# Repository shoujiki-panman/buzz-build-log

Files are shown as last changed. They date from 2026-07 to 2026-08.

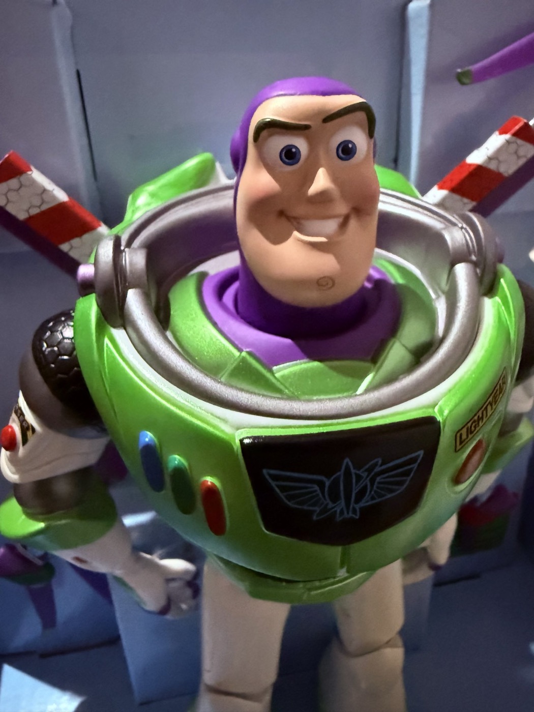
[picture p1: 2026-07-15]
buzz_photo.jpg

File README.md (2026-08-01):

# PROJECT BUZZ — 実フィギュアのバズを、本当に飛ばす

トイストーリーのバズ・ライトイヤーのアクションフィギュア（約264g）を、
実際に飛行するクアッドコプターに改造する個人プロジェクトのビルドログ。

- はんだ未経験の会社員が、AIと分担しながら作る「バイブコーディングをハードウェアに拡張する実験」
- 進捗はXで公開中: [#PROJECTBUZZ](https://x.com/hashtag/PROJECTBUZZ)
- **非営利のファンプロジェクト**です。キャラクターを使う成果物で収益化は行いません

## ゴール

**2026年10月末、バズが部屋を飛ぶ動画を1本公開する。**

進め方の原則: 計測→原因特定→1変更→検証 の1周を守る。シミュレータで通った＝実機OKとは考えない。
ハードは巻き戻せないため、各フェーズの合格条件（テスト）を満たすまで次に進まない。

## フェーズ（章立て）

| 章 | 内容 | 合格条件（=テスト） | 状態 |
|---|---|---|---|
| 第一章 | バズを目視で飛ばす（画面越しでなく自分の目で見て操縦） | 屋内で1分間の安定飛行 | **進行中**（調達完了・輸送待ち） |
| 第0.5章 | （廃止）操縦の練習は、シミュレータではなくテザー（命綱）で係留した実機で行う方針に変更 | — | 廃止（フェーズ8に統合） |
| 第二章 | 実機にFPVカメラを載せる準備 | — | 凍結（第一章の初飛行成功が条件） |
| 第三章 | AI自律飛行（専用実験機を想定） | 3モーションが実機で各1回成功 | 構想のみ。`sitl/` `motion/` が先行資産 |

### 第一章の詳細フェーズ（上から順に。1フェーズ完了→次へ）

各フェーズに **期日** を入れた。ゴール（11月の発表会）から逆算し、**2割の余裕**を持たせてある
（本来ギリギリの日付より1ヶ月手前に置く）。迷ったら、状態が「⬜次」の一番上の行が、いまやること。

| # | フェーズ | 期日（〜まで） | 誰が | やること | 合格条件（これで次へ） | 状態 |
|---|---|---|---|---|---|---|
| 1 | 発注 | 7/20 | オーナー | Futaba T6L（モード1）＋**受信機R3006SB**を注文（付属R3106GFはS.BUS非対応と判明・Issue #9） | 注文確定メール | ✅ **7/28発注済み**（8日遅れ・予備期間から充当） |
| 2 | 開封・検品 | 7/31 | オーナー | 全部品を開封し写真。モーターは手で回して異音チェック | 全部品そろい・破損なしの写真 | ✅ **7/29完了**（モーター4基・スタック・送信機T6L/受信機R3006SB。技適マーク001-A12854を実物確認） |
| 3 | 採寸 | 7/31 | オーナー→Claude | 素体264g確定・モーター実測済み・上蓋は共締め方式に変更（Issue #2） | 原寸紙型が実物と一致 | ✅ 設計反映済み（紙型照合はカーボン切り出し前に実施） |
| 3.4 | **実測** | **8/6** | オーナー | ノギス（8/4着）で羽根・背中・ジェットパックを測る（notes/MEASURE_LIST.md） | 表の空欄が埋まっている | ⬜ ノギス待ち |
| 3.5 | 発注 第2弾 | **8/8** | オーナー→Claudeがリンク準備 | プロペラ(紫)・バッテリー4S・充電器・ストリッパー・**デジタルノギス**=8/1注文済み。フレーム材はアルミに変更（3Dプリント・カーボン加工は廃止）→残りはホームセンターで**アルミ板＋平棒**（角パイプは設計変更で不要に。寸法は実測後に確定） | 全件の注文確定メール＋アルミ材購入 | 🔁 通販分✅・**実測後にホームセンター** |
| 4 | はんだ練習 | 8/10 | オーナー | 練習基板で10接点。玉が安定するまで | 玉の形が安定した写真 | ⬜ |
| 5 | 通電設定 | 8/17 | オーナー→Claude | スタックのBluetoothを無線オフに。USBでBetaflight設定 | 発煙なし・電圧正常・無線オフ確認 | ✅ **7/28前倒し完了**（BTFL 4.4.2接続・UART4オフ） |
| 6 | モーター回転確認 | 8/24 | オーナー | **ペラなし**で4モーターの回転方向を合わせる | 4基とも正しい向きで回る動画 | ⬜ |
| 7 | 素体ホバリング | **8/31** | オーナー | フィギュアなしの機体だけで浮かせる | 30秒の安定ホバリング動画 | ⬜ |
| 8 | バズ統合 | 9/21 | オーナー→Claude | バズを載せ、テザー（命綱）で係留して浮かせる | 係留状態で安定する動画 | ⬜ |
| 9 | 自由飛行・撮影 | **9/30** | オーナー | 屋内で目視飛行 | 1分の飛行動画（=第一章クリア） | ⬜ |

**発注第2弾の締切根拠**: カーボン板の切り出しは納期1〜2週間 → 素体ホバリング（8/31）から逆算して8/8注文が下限。
バッテリー・充電器はフェーズ6（モーター回転確認 8/24）までに初充電を済ませる必要があるため同時に買う。

**期日の意味（マイルストーン）:**
- **8/31 = 素体ホバリング**（フェーズ7）。ここが最重要関門。撤退基準「9月末までに浮かなければ縮小」より1ヶ月手前に置いてある＝失敗しても9月まるごとやり直せる
- **9/30 = 第一章クリア**（バズが飛ぶ）
- **10/15 = 動画完成**（公開の2週間前）／ **10月末 = 動画公開**
- **11月末（仮）= 発表会**。ここまでに全部終わり、発表練習だけの状態にする ← ⚠️正確な日付が分かり次第、全期日を前倒し調整

- **フェーズ7の前に必ず: 電波の運用ルール確認**（[Issue #7](../../issues/7)）。屋内限定・技適済みFutabaのみ使用
- 各フェーズ完了時に notes に「写真1枚＋一言」を残す（それが上の完了事項の表を育てる）
- **遅れたら**: 1フェーズ遅れるごとに、9月の予備1ヶ月から充当する。予備を使い切ったら仕様を落とす（重り妥協・自律を手動に・演出をテザー固定に）

### 設計・検証（Claude担当・荷物と並行して進む）

| 内容 | 状態 | 成果物 |
|---|---|---|
| トッププレート設計 | ✅ | [cad/top_plate.scad](cad/top_plate.scad) |
| 全体アセンブリの幾何チェック | ✅ | [cad/ASSEMBLY_CHECK.md](cad/ASSEMBLY_CHECK.md) |
| バズ3Dスキャン→メッシュ化 | ✅（v1。要トリミング） | [cad/buzz_mesh_v1.ply](cad/buzz_mesh_v1.ply) |
| スキャン2回目でメッシュ精度UP | ⬜ | 腕・支柱を近距離で撮り直す |
| アーム/モーターマウントのCAD | ⬜ 採寸後 | — |

### 発信トラック（ビルドと並走。作りっぱなしにせず毎週1本出す）

このプロジェクトは「作る」と「発信する」が並走する。ビルドの各フェーズが**そのまま動画の1話**になる。
毎週1本の制作サイクル = **撮る → 台本1枚 → 編集（縦型15〜45秒） → サムネ → 投稿**。

| 動画 | 何を撮る（対応フェーズ） | 投稿目安 |
|---|---|---|
| 開封の回 | フェーズ2 開封・検品 | 8月頭 |
| はんだの回 | フェーズ4 はんだ練習 | 8月中 |
| 初浮上の回 ★山場 | フェーズ7 素体ホバリング | 8月末 |
| 合体・テザーの回 | フェーズ8 バズ統合 | 9月中 |
| 初飛行の回 | フェーズ9 自由飛行 | 9月末 |
| **完成・本命動画** | フェーズ9後に決定版を撮り下ろし | **10月末（本公開）** |

**完成動画（本命）の制作フェーズ:**

| # | タスク | 期日 | 合格条件 |
|---|---|---|---|
| V1 | 絵コンテ（カット割り） | 10/5 | ショットリスト1枚 |
| V2 | 撮影（複数テイク・照明作り込み） | 10/10 | 全カットの使えるテイク |
| V3 | 編集（音・字幕・色） | 10/13 | 通しで目標尺に収まる |
| V4 | 検品・web圧縮 | 10/14 | スマホ再生OK |
| V5 | 公開 | **10月末** | 投稿・導線確認 |

- 「初めての瞬間」は撮り直せない。**物理作業の前に必ずスマホを回す**（開封・初はんだ・初浮上）
- 編集は製品デモ動画の作法（1画面1メッセージ・速いカット・キネティック字幕）を流用

## 完了事項

| 日付 | 内容 | 証跡 |
|---|---|---|
| 2026-07-07 | はんだ工具一式そろう | — |
| 2026-07-08 | シミュレータ環境（ArduPilot SITL）を構築。モーター始動→離陸→着陸の自動テスト合格 | [sitl/README.md](sitl/README.md) |
| 2026-07-08 | 飛行モーション3関数（急上昇・部屋一周・滑り込み着陸）がシミュレータ完走 | [motion/README.md](motion/README.md) |
| 2026-07-11 | 部品調達完了（輸送待ち）。素体実測264g・プロペラ対角210mm。設計を3インチ/X quadに確定 | スペック表 |
| 2026-07-12 | トッププレートのパラメトリック設計＋レンダリングで目視確認 | [cad/top_plate.scad](cad/top_plate.scad) |
| 2026-07-13 | 公開ビルドログ開設。機体全体の幾何チェック（プロペラ干渉なし・ポーズ制約を数値化） | [cad/ASSEMBLY_CHECK.md](cad/ASSEMBLY_CHECK.md) |
| 2026-07-14 | 電波法・航空法・電池を3省庁の一次情報で総点検し、操縦系を国産Futabaに確定 | [Issue #7](../../issues/7) |
| 2026-07-14 | バズをiPhoneで3Dスキャン→切り抜き→メッシュ化（Poisson再構成）。飾りプロペラ位置と実モーター位置が実寸で重なることを確認 | [cad/buzz_mesh_v1.ply](cad/buzz_mesh_v1.ply) |

## いま何をやるか（迷ったらここ）

**現在地: 第一章の準備フェーズ「荷物待ち」。** 全部品は発注済み・輸送中。手を動かす前の設計と法規制は片付いた。

**次の一手（この順に1つずつ）:**
1. **〜7/20 オーナー**: 操縦機 Futaba T6L Sport セット（モード1・国内正規品）を注文する → [Issue #9](../../issues/9)
2. **〜7/31 オーナー**: 荷物が届いたら開封して写真を撮る（検品の記録）
3. あとは上の「第一章の詳細フェーズ」の期日順に進む

**大きな締切**: 8/31 素体ホバリング（最重要関門）／ 9/30 バズが飛ぶ／ 10月末 動画公開／ 11月 発表会

詳細な作業は [Issues](../../issues) で管理（1 Issue = 1作業 = 完了条件つき）。

## テスト

**自動テスト（第三章資産・実行済み）**

| テスト | 内容 | 結果 |
|---|---|---|
| `sitl/smoke_test.py` | シミュレータ内で始動→5m離陸→着陸→停止 | ✅ PASSED（2026-07-08） |
| `sitl/demo_flight.py` | 3モーション（急上昇→部屋一周→滑り込み着陸）通し | ✅ PASSED（2026-07-08） |

再現手順は [sitl/README.md](sitl/README.md)。環境が壊れていないかは上の2本を流せば分かる。

**物理テスト（第一章）** は上の「第一章の詳細フェーズ」1〜9の合格条件がそのままテスト項目。フェーズ完了ごとに「写真1枚＋一言」で証跡を残す。

## 機体スペック（2026-07-11時点の設計）

| 項目 | 値 |
|---|---|
| ベースのフィギュア | バズ・ライトイヤー Transforming Action Figure（素体264g実測） |
| 構成 | X字クアッド、3インチ3枚ペラ |
| プロペラ位置の対角スパン | 約210mm（ダミープロペラ4本の実測。実質クアッド配置） |
| 想定全備重量 | 約440g |
| 飛行制御基板（FC/ESC） | SpeedyBee F405 Mini BLS 35A（20×20スタック） |
| モーター | T-Motor F2004 3000KV ×4 |
| 制御ソフト | Betaflight |
| 統合方針 | 純正上蓋は非破壊のまま、カーボントッププレートをM3で貫通固定。純正ブームに推力は載せない |

## リポジトリの中身

- [`cad/`](cad/) — カーボントッププレートのパラメトリック設計（OpenSCAD）＋プレビュー画像
- [`BUZZ_SCAN_GUIDE.md`](BUZZ_SCAN_GUIDE.md) — フィギュアをiPhoneで3Dスキャンする手順
- [`buzz_toystory_lp.html`](buzz_toystory_lp.html) — プロジェクトLP（※図面は初期案REV 0=5インチ時代。最新設計はこのREADMEが正）
- [`sitl/`](sitl/) / [`motion/`](motion/) — 第三章用の先行資産。ArduPilotシミュレータ環境と飛行モーション3関数

## 安全について

- はんだ・バッテリー運用・実飛行は人間が判断する（シミュレータで通った＝実機OKとは考えない）
- 電波法・航空法・電池の法規制は3省庁の一次情報で整理済み（[Issue #7](../../issues/7)）。運用ルール=屋内限定・技適済み機材のみ使用
- （第三章の自律飛行時）飛行プログラムには「人が介入したら即座に手を引く」処理を必ず入れる

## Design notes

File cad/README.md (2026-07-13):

# cad/ — 機体部品の設計データ

## top_plate.scad — カーボントッププレート（90×60×3mm）

引き継ぎ§6-1のトッププレート。OpenSCADのパラメトリック設計で、
**ファイル冒頭の数字を書き換えて保存すれば形が変わる**。

入っている穴:
- 中央: FCスタック用 20×20mm・M3（Φ3.5、シリコングロメット考慮）
- 四隅: アーム結合用 M3×2穴ずつ（45°対角線上。角パイプ/平棒どちらにも対応する土台）
- 純正上蓋への固定穴: **TODO(採寸待ち)** — 上蓋のボス・ネジ穴位置を実測したら
  `lid_holes = [[x, y], ...]` に書き足す

## 見方（3D画面で回して見る）

1. OpenSCADは導入済み（`/Applications/OpenSCAD-2021.01.app`、Homebrew経由）
2. `top_plate.scad` を開いて F5（プレビュー）
3. 発注用のSTLは F6（レンダリング）→ File > Export > STL

✅ 2026-07-12 目視確認済み。確認画像= `preview/top_plate_top.png`（真上）/ `preview/top_plate_iso.png`（斜め）。
画像の再生成: `openscad -o preview/top_plate_top.png --imgsize=900,1100 --projection=o --camera=0,0,0,0,0,0,260 top_plate.scad`

## まだ作っていないもの（引き継ぎ§6の残り、着手は実測後）

- §6-2 アーム→プレート結合ブラケット（3Dプリント・PETG）… アーム断面の決定待ち
- §6-3 モーターマウント（F2004、T-mount/M2）… モーター実物の採寸待ち
- §6-4 ダミープロペラ支柱の移植アダプタ … 支柱根元の採寸待ち
- §6-5 Blenderでの全体アセンブリ＋実写合成レンダ … バズ3Dスキャン(GLB)待ち

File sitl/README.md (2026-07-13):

# SITL環境構築・再現手順

ArduPilot SITL（Software In The Loop）をMac上で動かし、シミュレータ内のCopterが
ARM→離陸コマンドに反応するまでの手順。**2026-07-08にM5/32GB Mac（macOS 26.4）で構築・動作確認済み。**

- ArduPilot: `master` ブランチ `698a86fe2b`（ArduPilot-4.6.0-beta1-7396）
- Python: 3.10.18（pyenv、公式スクリプトが導入）／ MAVProxy: 1.8.74
- クローン先: `~/ardupilot`（このリポジトリの外。約3GB）

## 1. セットアップ（公式手順）

公式: https://ardupilot.org/dev/docs/building-setup-mac.html

```bash
# 前提: Xcode Command Line Tools と Homebrew が入っていること
git clone --recurse-submodules https://github.com/ArduPilot/ardupilot.git ~/ardupilot
cd ~/ardupilot
./Tools/environment_install/install-prereqs-mac.sh -y
```

スクリプトが `~/.zshrc` にpyenv等のPATH設定を追記する。実行後は**新しいターミナルを開く**か
`source ~/.zshrc` して反映する。

### この環境で踏んだ罠（2026-07-08）

1. **`.zshrc` のbun補完でスクリプトが途中死する**
   スクリプトはbashで動き、途中で `~/.zshrc` をsourceする。zsh専用のbun補完
   （`source ~/.bun/_bun`）がbashでsyntax errorになり、`set -e` で静かに止まった
   （pyenvインストール直後、pipパッケージ導入前）。
   → 対処: pyenvをPATHに載せて再実行すると、問題のsource行を通らず完走する。
   ```bash
   export PYENV_ROOT="$HOME/.pyenv"; export PATH="$PYENV_ROOT/bin:$PATH"
   ./Tools/environment_install/install-prereqs-mac.sh -y
   ```
2. **STM32ツールチェーンのインストールでsudoパスワードを要求される**
   SITLには不要（実機FC用ファームを手元でビルドする時だけ必要。本計画のFWは
   Custom Buildサーバー利用予定なので当面不要）。
   → 対処: `DO_AP_STM_ENV=0` を付けてスキップ（スクリプト公式の環境変数。
   対話実行時のデフォルトもNなので挙動は公式どおり）。
   ```bash
   DO_AP_STM_ENV=0 ./Tools/environment_install/install-prereqs-mac.sh -y
   ```
3. **`mavproxy.py` が見つからない場合**は `pyenv rehash` を実行する。

## 2. ビルド

```bash
cd ~/ardupilot
./waf configure --board sitl
./waf copter        # M5で約1分45秒。build/sitl/bin/arducopter ができる
```

## 3. 起動と離陸テスト（手動・公式チュートリアル）

公式: https://ardupilot.org/dev/docs/copter-sitl-mavproxy-tutorial.html

```bash
cd ~/ardupilot/ArduCopter
sim_vehicle.py --console --map -w   # 初回のみ -w（仮想EEPROMを初期化）
```

MAVProxyのプロンプトで:

```
mode guided
arm throttle      # EKF準備完了前はPreArmで弾かれる。起動後30秒ほど待って再実行
takeoff 5         # ⚠️ armから15秒以内に打つこと（過ぎると自動disarm）
mode land
```

## 4. 起動と離陸テスト（自動・スモークテスト）

上記の手順をそのまま自動化したのが [smoke_test.py](smoke_test.py)。環境が壊れていないかの確認に使う。

```bash
python3 sitl/smoke_test.py      # リポジトリルートから
```

成功すると `SMOKE TEST PASSED` / exit 0。
初回実行結果（2026-07-08）: GUIDED→ARM→4.7m到達→LAND→disarm まで通過 ✅

## TODO

- [ ] Gazebo連携（3Dビジュアル検証。Luaの軌道確認を目視したくなった段階で追加）
- [ ] Lua 3関数の骨格（burst_takeoff / room_loop / swoop_land）をSITLで動かす — 次セッション

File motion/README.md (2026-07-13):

# バズの飛び方3つ（デモのやり方）

[buzz_motion.lua](buzz_motion.lua) は、シミュレータの中のドローンに
バズの飛び方3つをさせるプログラム。**2026-07-08にシミュレータで3つとも動作確認済み。**

| 番号 | 名前 | 動き |
|---|---|---|
| 1 | burst_takeoff | 垂直に急上昇（ベッドから飛び立つやつ） |
| 2 | room_loop | 部屋をぐるっと一周して中心に戻る |
| 3 | swoop_land | 前に滑り込みながら降りて、ゆっくり着地 |

まだ「骨格版」: 部屋一周は四角く直線で回っているだけ。バンクターン（傾けて曲がる）や
スピード感は、部屋の実測が済んでから本実装する。

## デモのやり方（画面に地図を出して見せる）

ターミナルで:

```bash
cd ~/ardupilot/ArduCopter
sim_vehicle.py --console --map --add-param-file=<このリポジトリ>/sitl/buzz_sitl.parm
```

地図とコンソールの窓が開く。1分ほど待って（GPSをつかむまで）、ターミナルに順番に打つ:

```
mode guided
arm throttle
param set SCR_USER1 1     ← 急上昇
param set SCR_USER1 2     ← 部屋一周（地図をズームすると四角く動くのが見える）
param set SCR_USER1 3     ← 滑り込んで着地
```

コンソールに `BUZZ: ...` というメッセージが出て進行がわかる。
部屋は4m×3mの想定なので、地図はかなりズームしないと動きが見えない。

## 途中で止めたいとき

- スティック（送信機）を動かす、またはモードを変える → プログラムは即座に手を引く
- これは実機でも同じ動きにする約束（人間がいつでも取り返せる）

## いじって遊べる数字（buzz_motion.lua の頭にある）

| 名前 | 今の値 | 意味 |
|---|---|---|
| ROOM_X / ROOM_Y | 4.0 / 3.0 | 部屋の大きさ(m)。**実測待ち** |
| BURST_ALT | 2.0 | 急上昇の高さ(m)。**天井の実測待ち** |
| SWOOP_ALT | 0.8 | 着地前に滑り込む高さ(m) |
| BANK_ANGLE | 20 | 旋回の傾き(度)。骨格版ではまだ使っていない |

数字を変えたら保存して、シミュレータを起動し直すと反映される。

## 自動チェック（環境が壊れていないか確認したいとき）

上のデモと同じ操作を機械が全部やる:

```bash
python3 sitl/demo_flight.py    # リポジトリルートから。成功すると DEMO FLIGHT PASSED
```

## 仕組みメモ（1行ずつ）

- プログラムは `~/ardupilot/ArduCopter/scripts/` にリンクを置いてある（`ln -sf <このリポジトリ>/motion/buzz_motion.lua ~/ardupilot/ArduCopter/scripts/`）
- `SCR_USER1` は「スクリプト用の空きパラメータ」。地上局から数字を送るボタン代わりに使っている
- 本実装でやること: バンクターン・スピード調整・部屋寸法の実測値反映・実機用の安全チェック追加

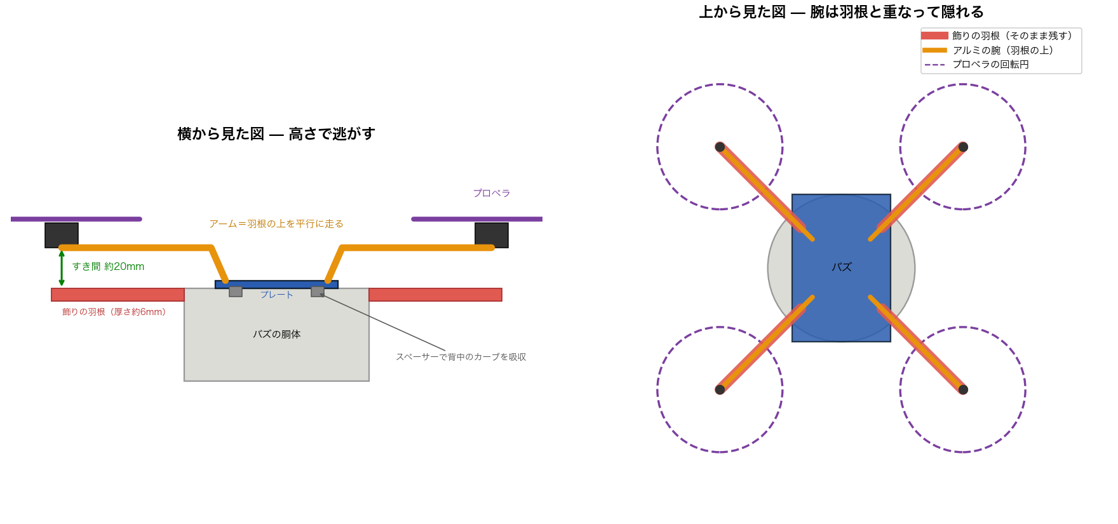
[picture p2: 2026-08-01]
media/wing_preserve_design.png

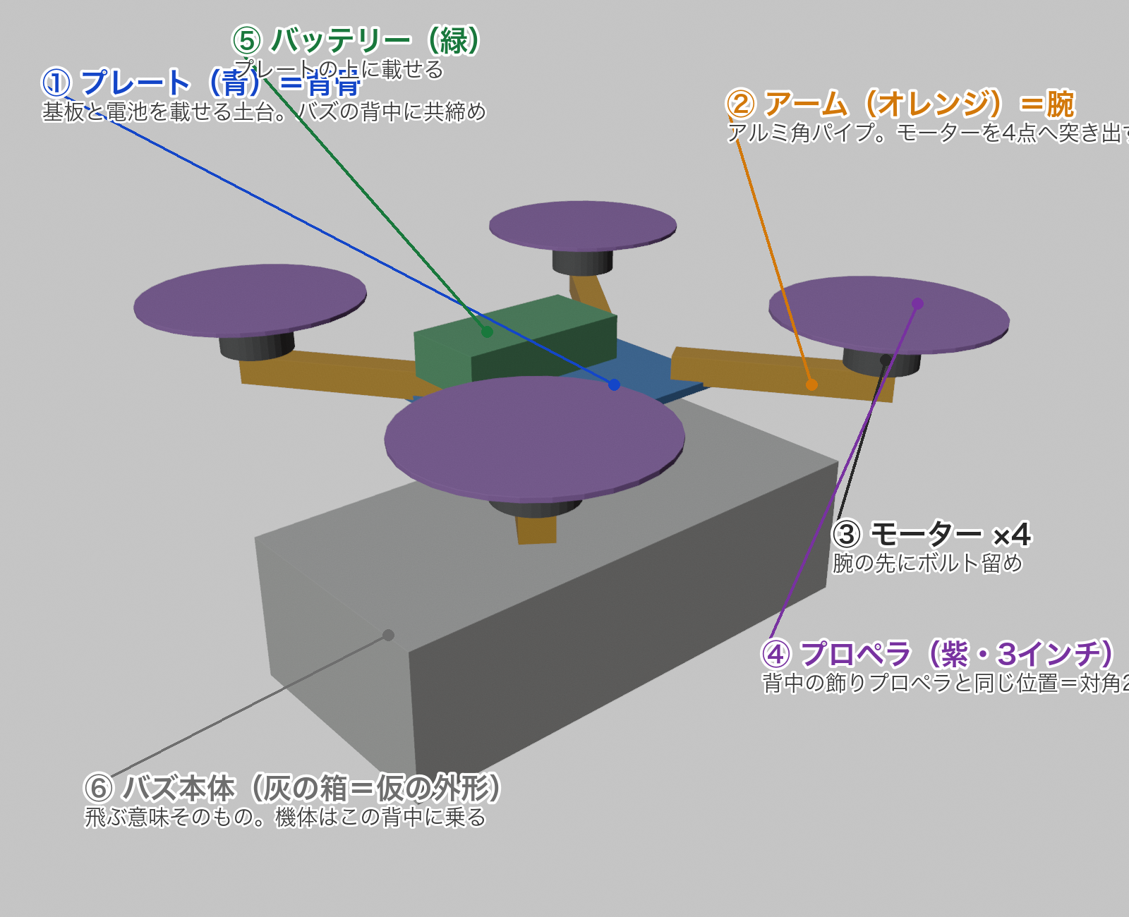
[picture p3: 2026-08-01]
media/anatomy_v1.png

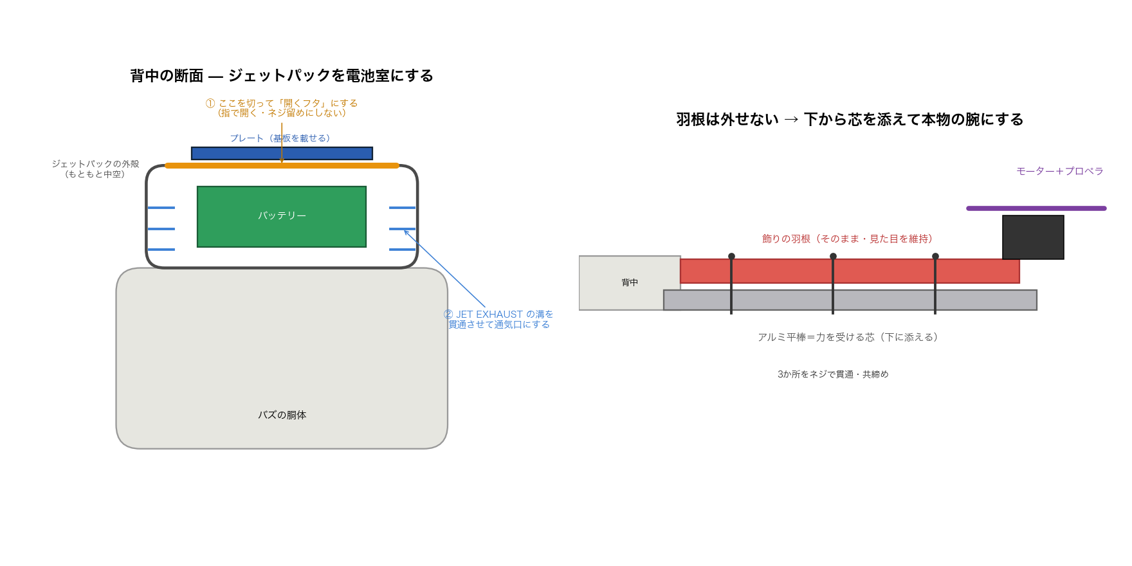
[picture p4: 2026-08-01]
media/jetpack_bay.png

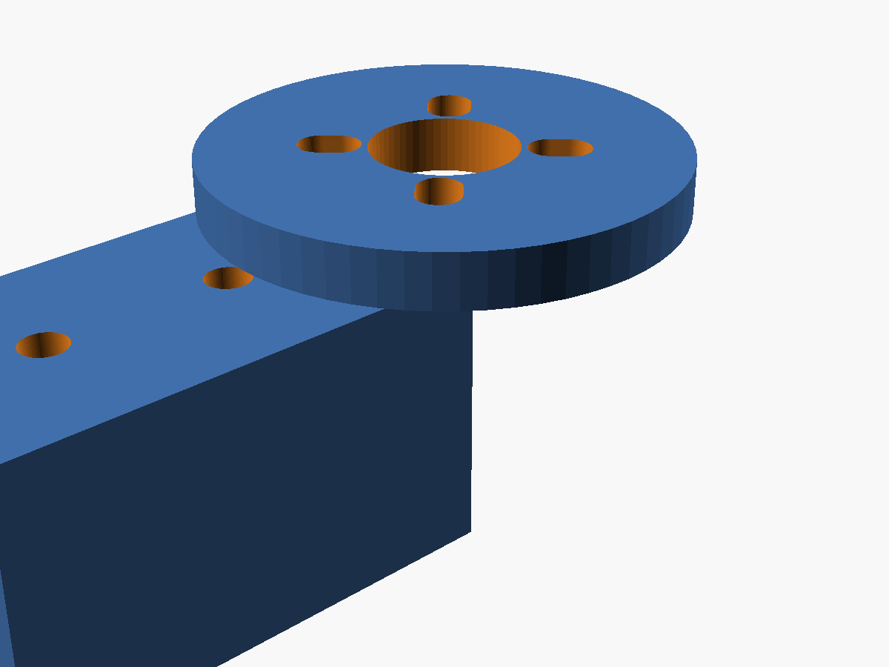
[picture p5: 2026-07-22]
media/motor_mount_iso.png

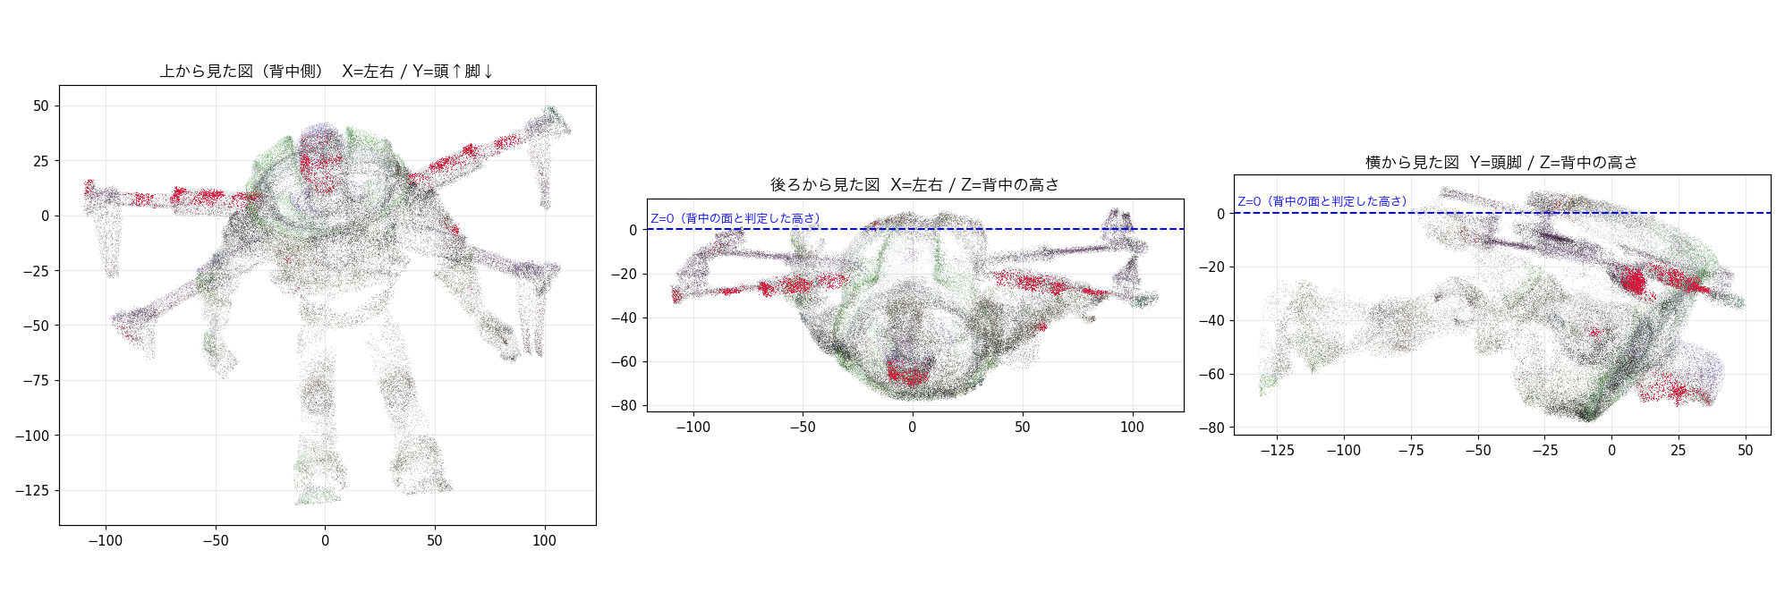
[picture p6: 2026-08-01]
media/scan_cleaned.png

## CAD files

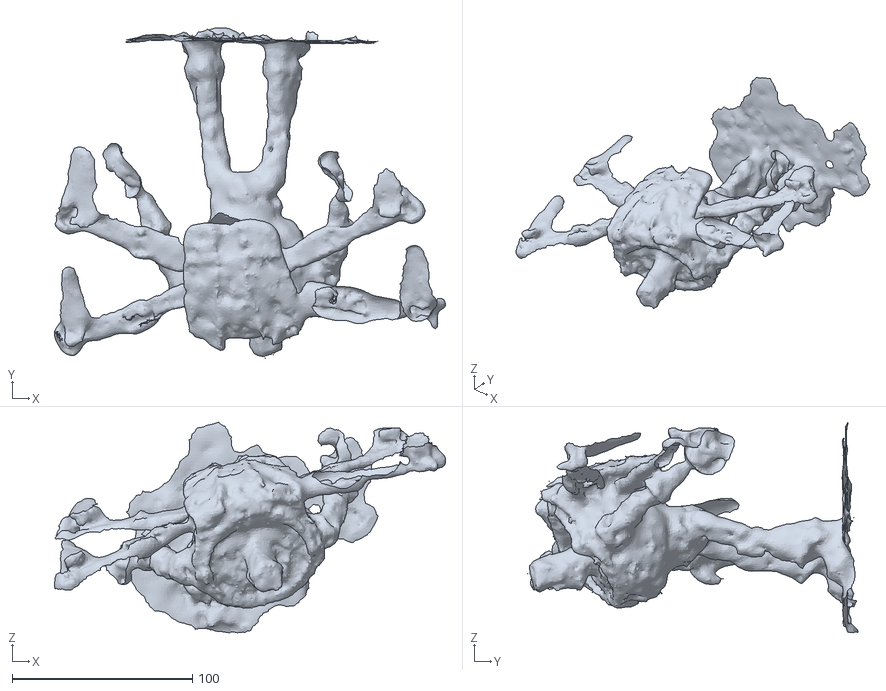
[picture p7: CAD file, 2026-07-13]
cad/buzz_mesh_v1.ply
217.1 x 183.4 x 117.0

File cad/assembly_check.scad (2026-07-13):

// assembly_check.scad — 機体全体の幾何チェック（組み上がるかの証拠）
// 実測値と確定部品で全体を組み、プロペラ干渉と寸法の整合を目で確認する。
// 「仮定」印の数字はバズの実測（Issue #1, #2）で差し替える。

$fn = 48;

// ==== 実測・確定値 ==========================================
prop_diag = 210;                  // ダミープロペラ対角スパン（実測）
motor_xy  = prop_diag / 2 / sqrt(2);  // モーター位置 = ±74.2mm
prop_d    = 76.2;                 // 3インチプロペラ直径（確定構成）
plate_w = 60; plate_l = 90; plate_t = 3;   // トッププレート（設計済み）

// ==== 部品の想定寸法 ========================================
arm_w = 10; arm_t = 10;           // カーボン角パイプ10×10（両対応案の片方）
motor_d = 25; motor_h = 15;       // F2004クラスの外形
prop_z  = plate_t + motor_h + 4;  // プロペラ回転面の高さ

// ==== バズの外形（★仮定 — 実測で差し替え）==================
buzz_l = 195;   // 全高195mm（実測: 19.5cm）→ うつ伏せ飛行姿勢で前後方向
buzz_w = 90;    // ★仮定: 腕を体側に沿わせたポーズの最大幅
buzz_t = 55;    // ★仮定: 胸の厚み
lid_h  = 40;    // ★仮定: ジェットパック上蓋からバズ背面までの高さ

// ==== 電池（重心調整の可変要素）=============================
batt = [30, 60, 15]; batt_y = -20;   // プレート上・前後に動かせる

// ==== 検算をコンソールに出す ================================
echo(str("モーター位置: ±", motor_xy, "mm（対角", prop_diag, "mm）"));
echo(str("隣接プロペラの隙間: ", prop_diag/sqrt(2) - prop_d, "mm（>0で干渉なし）"));
echo(str("プロペラ円の内側の縁: 中心から", motor_xy - prop_d/2, "mm（体の幅はこの内側×2に収める）"));

// ==== モデル ================================================
// トッププレート
color("gray") linear_extrude(plate_t)
  offset(r=6) square([plate_w-12, plate_l-12], center=true);

// アーム4本（プレート角→モーター位置、45°）
for (sx=[-1,1], sy=[-1,1])
  color([0.2,0.2,0.2])
    hull() {
      translate([sx*22, sy*37, plate_t/2]) cube([arm_w, arm_w, arm_t], center=true);
      translate([sx*motor_xy, sy*motor_xy, plate_t/2]) cube([arm_w, arm_w, arm_t], center=true);
    }

// モーター4基
for (sx=[-1,1], sy=[-1,1])
  color("orange") translate([sx*motor_xy, sy*motor_xy, plate_t])
    cylinder(d=motor_d, h=motor_h);

// プロペラ回転面（半透明の円盤）
for (sx=[-1,1], sy=[-1,1])
  color([1,0,0,0.35]) translate([sx*motor_xy, sy*motor_xy, prop_z])
    cylinder(d=prop_d, h=1.5);

// 電池
color("green") translate([0, batt_y, plate_t + arm_t])
  cube(batt, center=true);

// バズ（うつ伏せ・上蓋の下にぶら下がる想定の外形箱）
color([0.3,0.5,1,0.55]) translate([0, 0, -lid_h - buzz_t/2])
  cube([buzz_w, buzz_l, buzz_t], center=true);
// 頭の目印（+Y側）
color([0.3,0.5,1,0.7]) translate([0, buzz_l/2 - 20, -lid_h - buzz_t/2])
  sphere(d=45);

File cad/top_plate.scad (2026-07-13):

// PROJECT BUZZ — カーボントッププレート（パラメトリック）
// 引き継ぎ§6-1: 90×60×3mm。座標系は原寸テンプレPDF準拠（中心原点、モーターは±74mm対角＝板の外）。
// 冒頭の数字をいじって保存すれば形が変わる。実測が来たら TODO の行に値を入れる。

$fn = 64;

// ==== 板そのもの ============================================
plate_w  = 60;   // 横幅 (X) mm — ジェットパック上蓋(横65〜70)より少し小さく
plate_l  = 90;   // 縦   (Y) mm — 上蓋(縦100〜110)より少し小さく
plate_t  = 3;    // 板厚 mm（3mmカーボン想定）
corner_r = 6;    // 角の丸み

// ==== FCスタック穴（SpeedyBee F405 Mini = 20×20 M3）=========
stack_pitch  = 20;
stack_hole_d = 3.5;  // M3ボルト＋シリコングロメット径を考慮

// ==== アーム結合穴（四隅、45°対角線上に各2穴）================
// アーム断面は未確定（カーボン角パイプ10×10 or 平棒）のため、
// どちらでも使える「対角線上のM3穴2個」をベースにする。
// 角パイプの場合は別部品のブラケット（§6-2、3Dプリント）で挟む。
arm_hole_d = 3.2;          // M3通し
arm_hole_r = [26, 36];     // 中心からの距離 mm（対角線上）。ブラケット設計に合わせて調整可

// ==== 純正上蓋への固定ボルト穴 ================================
// TODO(採寸待ち): 上蓋のボス位置・ネジ穴位置を実測したら [x, y] を追記する
// 例: lid_holes = [[-20, 35], [20, 35], [-20, -35], [20, -35]];
lid_holes  = [];
lid_hole_d = 3.2;

// ==== 形状 ====================================================
module plate_2d() {
  offset(r = corner_r)
    square([plate_w - 2 * corner_r, plate_l - 2 * corner_r], center = true);
}

module holes_2d() {
  // FCスタック 20×20
  for (sx = [-1, 1], sy = [-1, 1])
    translate([sx * stack_pitch / 2, sy * stack_pitch / 2])
      circle(d = stack_hole_d);

  // アーム結合（四隅の対角線上に各2穴）
  for (sx = [-1, 1], sy = [-1, 1], r = arm_hole_r)
    translate([sx * r * cos(45), sy * r * sin(45)])
      circle(d = arm_hole_d);

  // 純正上蓋への固定（採寸後に lid_holes へ追記すると穴が開く）
  for (p = lid_holes)
    translate(p)
      circle(d = lid_hole_d);
}

linear_extrude(height = plate_t)
  difference() {
    plate_2d();
    holes_2d();
  }

// 参考: モーター中心は (±74, ±74) = 対角スパン210mm（板の外側、アーム先端）
echo(str("plate ", plate_w, "x", plate_l, "x", plate_t,
         "mm / stack 20x20 / arm holes r=", arm_hole_r,
         " / lid holes: ", len(lid_holes), "個（採寸待ち）"));

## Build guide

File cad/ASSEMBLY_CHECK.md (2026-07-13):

# 機体全体の幾何チェック（2026-07-13）

「そもそも組み上がるのか」を、実測値と確定部品の3Dモデルで検証した結果。
モデル= [assembly_check.scad](assembly_check.scad) ／ 画像= [真上](preview/assembly_top.png)・[斜め](preview/assembly_iso.png)

## 判定: 幾何学的には成立する。ただし条件が2つ数字で出た

### 確認できたこと（実測・確定値ベース）

| 項目 | 数字 | 判定 |
|---|---|---|
| 隣接プロペラ同士の隙間 | **72mm** | ✅ 干渉なし（余裕大） |
| プロペラ円とトッププレート | 重ならない | ✅ 干渉なし |
| プロペラ回転面の高さ | バズ背面から約+60mm上 | ✅ 胴体とは立体的に分離 |

### 出てきた条件（ここが本当の発見）

1. **ポーズ制約が数字になった**: プロペラ円の内側の縁は機体中心から**36mm**。
   バズの体はこれより幅広（肩・腕）なので、真上から見るとプロペラ円の下に体がかかる。
   垂直方向の逃げ（約60mm）で成立しているため、**幅36mmより外側にある部位（腕・翼の飾り）を
   背面から上に55mm以上立ち上げてはいけない**。→ 腕は体側に沿わせるポーズ一択。Tポーズ不可
2. **重心の吸収幅が数字になった**: 電池（75g）はプレート上で前後±35mmしか動かせないため、
   吸収できるのは**バズ単体の重心ズレ±10mmまで**（264g × ズレ ÷ 電池75g ≒ 3.5倍のテコが必要）。
   ズレがそれ以上なら、マウント位置そのものをずらして補正する設計になる。
   → **Issue #1（単体重心の実測）が機体設計の最重要インプット**だと判明

### まだ仮定の数字（実測で差し替え — Issue #1, #2に対応）

| 仮定 | 置いた値 | 実測方法 |
|---|---|---|
| 体の最大幅（腕を体側ポーズ） | 90mm | 定規 |
| 胸の厚み | 55mm | 定規 |
| 上蓋からバズ背面までの高さ | 40mm | 定規 |
| 単体の重心位置 | 中心と仮定 | 吊り下げ（Issue #1） |

## 使い方

数字を直したら再生成:
```
openscad -o preview/assembly_top.png --imgsize=1000,1000 --projection=o --camera=0,0,-40,0,0,0,500 assembly_check.scad
openscad -o preview/assembly_iso.png --imgsize=1100,800 --camera=0,0,-30,60,0,35,520 assembly_check.scad
```

## 正直な注記

- このチェックが証明するのは**幾何（寸法の整合）と重心の計算**まで。はんだの成否・振動・
  実飛行の安定は物理でしか分からない（そのための段階ゲート）
- バズは箱で近似している。実物の形での最終確認は、実測値の反映＋（任意で）3Dスキャン合成で行う

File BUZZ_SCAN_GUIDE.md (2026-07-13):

# BUZZ_SCAN_GUIDE.md — バズ3Dスキャン手順(人間用)

> これはClaude Codeではなくシュさんが実施するタスク。
> 完了したらGLBファイルをプロジェクトフォルダに置き、BUZZ_3D_TASK.mdをClaude Codeに投げる。

## なぜスキャンするか(目的の再確認)

- **作るイメージを掴むため**: 画面の中にバズ+プロペラ円4つが浮かんだ瞬間、「できる」という確信に変わる。ここが発注・採寸を進める起点
- **BootCampで見せる3Dモデル**になる(出どころが自分なのでIP的にクリーン)
- 飛ばすだけなら必須ではない。ただしシュさんの勝ちパターン(まず見える形→中身を詰める)に沿った正しい一手

## 使うもの

- iPhone + **Scaniverse**(無料、App Store)
- 柄のある紙or新聞紙(バズの足元に敷く)
- あれば: ベビーパウダー(テカり対策)、ノギス(スキャン後の検証用)

## 準備(2分)

1. バズのヘルメットを外す(透明パーツはスキャンに写らない。ドームは後でBlenderで球体を足せばOK)
2. テーブル中央にバズを立たせ、周囲をぐるっと歩けるスペースを確保
3. 足元に柄のある紙を敷く(背景との融合防止・トラッキング安定)
4. 照明は部屋全体が明るく均一に。窓際の間接光か天井灯。直射・スポットライトはNG

## スキャン(5〜10分)

1. Scaniverseで **New Scan → Small Object** を選択
2. バズから **30〜40cm** の距離を保ち、**とにかくゆっくり** 1周
3. 高さを変えてさらに2周:
   - 見下ろしアングルで1周
   - 見上げ気味で1周
4. 影になりやすい部分(腕の下・ジェットパックの裏・股下)は個別に近づいてゆっくりなめる

## 処理と書き出し(3分)

1. スキャン終了 → 処理モードは **Detail** を選択
2. Share → Export Model → **GLB (glTF)** で書き出し
3. AirDropでMacへ → プロジェクトフォルダに `buzz_scan_v1.glb` として保存

## よくある失敗と対策

| 症状 | 対策 |
|---|---|
| 白スーツがテカって表面が波打つ | ベビーパウダーを薄くはたく(後で拭ける) |
| 足元が背景と融合して溶ける | 柄のある紙を敷く |
| 細い腕・アンテナが欠ける | その部分だけ30cm以内に近づいてゆっくり周回 |
| 全体がガタガタ | 動きが速すぎ。半分の速度でやり直し |

## 期待値の置き方

- **1回目はラフでOK**。どこが崩れるか把握 → 対策して2回目で仕留める二段構え
- 設計検証に必要なのは寸法とシルエットの正確さ。テクスチャの荒れは無視してよい
- 見栄えはスキャン後にBlenderでリメッシュ+スムージングで化ける
- Scaniverseで物足りなければ、RealityScanやReality Composer(Mac)で再構築する手もある

## 完了チェック

- [ ] `buzz_scan_v1.glb` がMacのプロジェクトフォルダにある
- [ ] 全高をノギスで実測してメモした(Blenderでのスケール合わせに必須): ___ mm
- [ ] BUZZ_STATE.mdの「📍現在地」を更新した
- [ ] 次: BUZZ_3D_TASK.mdをClaude Codeに投げる(Blender MCPセットアップから)

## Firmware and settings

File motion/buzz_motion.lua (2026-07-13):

-- buzz_motion.lua — バズの飛び方3つ（骨格版）
--
-- 3つの動き:
--   burst_takeoff : 垂直に急上昇（ベッドから飛び立つやつ）
--   room_loop     : 部屋をぐるっと一周（今は四角く回る。傾き旋回は本実装で）
--   swoop_land    : 前に滑り込みながら降りて、ゆっくり着地
--
-- 動かし方（地上局から）:
--   GUIDEDモードでarmしたあと、SCR_USER1 という数字を変えると動く
--     SCR_USER1 = 1 → burst_takeoff
--     SCR_USER1 = 2 → room_loop
--     SCR_USER1 = 3 → swoop_land
--
-- 安全ルール（CLAUDE.mdの約束）:
--   人がスティックを動かす・モードを変える・disarmする → 即座に手を引いてIDLEに戻る
--   このスクリプトは自分からarmしない（armは必ず人がやる）

-- ==== いじって遊べる数字（すべてメートル）====================
local ROOM_X    = 4.0  -- TODO(実測待ち): 部屋の奥行き
local ROOM_Y    = 3.0  -- TODO(実測待ち): 部屋の幅
local MARGIN    = 0.8  -- 壁からどれだけ離れるか
local BURST_ALT = 2.0  -- TODO(実測待ち): 急上昇の高さ（天井に合わせる）
local SWOOP_ALT = 0.8  -- 着地前にここまで滑り込む高さ
local BANK_ANGLE = 20  -- TODO: 骨格では未使用。本実装で旋回の傾き(度)に使う
-- ============================================================

local MODE_GUIDED = 4
local MODE_LAND   = 9
local WP_RADIUS   = 0.6   -- 「目標に着いた」とみなす距離(m)
local RC_DEADZONE = 150   -- スティック検知のあそび(PWM)

local state = "IDLE"
local wps = {}       -- room_loop のウェイポイント一覧
local wp_i = 0

local function say(msg)
  gcs:send_text(6, "BUZZ: " .. msg)
end

-- 人がスティック（ロール/ピッチ/ヨー）を動かしたか
local function pilot_moved_stick()
  for _, ch in ipairs({1, 2, 4}) do
    local pwm = rc:get_pwm(ch)
    if pwm and pwm > 900 and math.abs(pwm - 1500) > RC_DEADZONE then
      return true
    end
  end
  return false
end

-- 高さ（離陸地点から何m上か）
local function height_m()
  local pos = ahrs:get_relative_position_NED_home()
  if pos then return -pos:z() end
  return nil
end

-- 今いる場所から部屋の四隅ウェイポイントを作る（自分＝部屋の中心と仮定）
local function build_room_wps()
  local here = ahrs:get_location()
  if not here then return false end
  local dx = ROOM_X / 2 - MARGIN
  local dy = ROOM_Y / 2 - MARGIN
  wps = {}
  local corners = { {dx, dy}, {dx, -dy}, {-dx, -dy}, {-dx, dy}, {0, 0} }
  for _, c in ipairs(corners) do
    local wp = here:copy()
    wp:offset(c[1], c[2])
    table.insert(wps, wp)
  end
  wp_i = 0
  return true
end

local function next_wp()
  wp_i = wp_i + 1
  if wp_i > #wps then return false end
  vehicle:set_target_location(wps[wp_i])
  say(string.format("room_loop wp %d/%d", wp_i, #wps))
  return true
end

-- 目標地点まであと何m（横方向）
local function dist_to_wp()
  local here = ahrs:get_location()
  if not here or wp_i < 1 or wp_i > #wps then return nil end
  return here:get_distance(wps[wp_i])
end

local function abort_to_idle(reason)
  state = "IDLE"
  say("STOP (" .. reason .. ") -> hands off, pilot has control")
end

function update()
  -- 安全チェック: 動作中に人が介入したら即座に手を引く
  if state ~= "IDLE" and state ~= "LANDING" then
    if pilot_moved_stick() then abort_to_idle("stick input") return update, 100 end
    if vehicle:get_mode() ~= MODE_GUIDED then abort_to_idle("mode change") return update, 100 end
    if not arming:is_armed() then abort_to_idle("disarmed") return update, 100 end
  end
  if state == "LANDING" and pilot_moved_stick() then
    abort_to_idle("stick input")
    return update, 100
  end

  -- 地上局からの指示（SCR_USER1）を読む
  local cmd = param:get('SCR_USER1')
  cmd = cmd and math.floor(cmd) or 0
  if cmd ~= 0 then
    param:set('SCR_USER1', 0)  -- 一回読んだらリセット（ボタンのように使う）
    if state ~= "IDLE" then
      say("busy (" .. state .. "), command ignored")
    elseif vehicle:get_mode() ~= MODE_GUIDED or not arming:is_armed() then
      say("need GUIDED + armed first")
    elseif cmd == 1 then
      if vehicle:start_takeoff(BURST_ALT) then
        state = "TAKEOFF"
        say(string.format("burst_takeoff -> %.1fm", BURST_ALT))
      else
        say("takeoff refused")
      end
    elseif cmd == 2 then
      if build_room_wps() and next_wp() then
        state = "LOOP"
        say("room_loop start")
      end
    elseif cmd == 3 then
      local here = ahrs:get_location()
      local h = height_m()
      if here and h then
        local wp = here:copy()
        wp:offset(ROOM_X / 2 - MARGIN, 0)          -- 前方へ滑り込む
        wp:alt(wp:alt() - math.floor((h - SWOOP_ALT) * 100))  -- alt はcm単位
        vehicle:set_target_location(wp)
        state = "SWOOP"
        say("swoop_land start")
      end
    end
  end

  -- 各動きの進行チェック
  if state == "TAKEOFF" then
    local h = height_m()
    if h and h >= BURST_ALT - 0.3 then
      state = "IDLE"
      say("burst_takeoff done")
    end
  elseif state == "LOOP" then
    local d = dist_to_wp()
    if d and d < WP_RADIUS then
      if not next_wp() then
        state = "IDLE"
        say("room_loop done")
      end
    end
  elseif state == "SWOOP" then
    -- 滑り込みで高度が下がりきったら着陸モードへ
    local h = height_m()
    if h and h <= SWOOP_ALT + 0.3 then
      vehicle:set_mode(MODE_LAND)
      state = "LANDING"
      say("swoop_land: LAND")
    end
  elseif state == "LANDING" then
    if not arming:is_armed() then
      state = "IDLE"
      say("swoop_land done (disarmed)")
    end
  end

  return update, 100  -- 0.1秒ごとに繰り返す
end

-- 起動時: 押しっぱなしのボタンが残っていても無視する
param:set('SCR_USER1', 0)
say("motion script ready (1=takeoff 2=loop 3=land)")

return update()

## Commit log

2026-07-13 PROJECT BUZZ 公開ビルドログ: 設計・スキャン手順・第三章資産（予算・個人メモは含まない)
    [buzz_sitl.parm, top_plate.scad]
2026-07-13 README拡充: ゴール・フェーズ合格条件・完了事項・テスト状況
2026-07-13 READMEの専門用語を初出で噛み砕く（誰が読んでもわかる基準）
2026-07-13 全体アセンブリの幾何チェックを追加（干渉判定・ポーズ制約・重心の吸収幅）
    [assembly_check.scad]
2026-07-13 スキャン→メッシュ化の成果物を追加（buzz_mesh_v1.ply + 生成スクリプト + プレビュー）
    [buzz_mesh_v1.ply]
2026-07-13 README: 今日の成果を完了事項に追記＋第一章を詳細フェーズ表に＋「いま何をやるか」節を新設
2026-07-13 フェーズに期日を追加（11月発表会から2割バッファで逆算）
    - 各フェーズに「〜まで」の期日。8/31素体ホバ・9/30飛行・10末公開
    - マイルストーンと遅延時の充当ルールを明記
    - 11月発表会は正確な日付待ち（確定後に全期日を前倒し調整）
2026-07-13 発信トラックを追加: ビルドと並走する動画制作フェーズと期日
    - 各ビルドフェーズ→動画1話の対応表
    - 完成動画(本命)の制作フェーズV1-V5に期日
    - Issue #11(毎週動画)#12(完成動画)を新設
2026-07-13 古くなった記述の整合: 今日の方針転換をREADME全体に反映
    - 第0.5章（シミュレータ）を廃止と明記（練習はテザー実機に変更済み）
    - テスト節の「物理ゲート」参照切れを「詳細フェーズ1〜9」に更新
    - 安全節: 法規制は整理済み（Issue #7）と完了形に、即時停止処理は第三章限定と明記
    - 「いま何をやるか」の節名参照を正確に
2026-07-15 LPを現状に更新（3インチ・実測値・REV 1・キャッチコピー変更）
2026-07-15 LPに第2弾（光る+話す）のアニメーションを追加
2026-07-15 LPから正直パンマンvoiceの記載を削除
2026-07-15 LPに主役の実物写真とClaude Code協働の一文を追加
2026-07-15 LPに使う部品と法規制のルール3つを追加
2026-07-22 モーターマウント設計v1のプレビュー画像を追加
2026-07-26 FreePencil2による組立CADの線画v1（Blender 5.1ローカルパッチで生成）
2026-07-27 フェーズ表を実態に更新: 検品✅・通電設定✅前倒し・発注は遅れ表示
2026-07-27 フェーズ1完了: 送信機・受信機を発注（7/28）
2026-07-27 フェーズ表に発注第2弾（8/8締切）を追加
2026-07-28 アームブラケットのプレビュー画像を追加
2026-07-29 LPを公開用に準備: index.html にリネームし、検索避け(noindex)を追加 (#13)
    - buzz_toystory_lp.html → index.html（GitHub Pagesのトップに出すため）
    - <meta name="robots" content="noindex, nofollow"> を追加。
    robots.txtで締め出すとこの指示自体が読まれず、外部リンク経由でURLだけ
    索引される事故が起きるため、クロールは許可してページ側で拒否する
    - .nojekyll を追加し、README等のmdがページ化されないようにする
2026-08-01 フェーズ2・3完了: 送受信機着荷と技適確認、採寸は設計反映済み
2026-08-01 発注第2弾: 通販分完了（8/1）、残りはホームセンターのアルミ材のみ
2026-08-01 機体の解剖図（部品の役割の色分け注釈つき）を追加
2026-08-01 羽根を残す設計案と、スキャンによる干渉確認図を追加
2026-08-01 ジェットパックを電池室にする案と羽根補強の図を追加
2026-08-01 発注第2弾にノギスを追記
2026-08-01 フェーズ表に実測(3.4)を追加し、発注第2弾の内容を現行設計に合わせて修正
